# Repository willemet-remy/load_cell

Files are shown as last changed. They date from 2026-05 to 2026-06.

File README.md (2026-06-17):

# Beaker Load Cell Monitoring System

This repository contains the complete open-source hardware designs, ESP32 microcontroller firmware, and Python-based graphical user interface (GUI) for a 4-channel weight scale system. 

The system is designed to monitor the outflow of up to four 500 mL beakers filling gradually with water. It is suited for laboratory setups requiring continuous measurements, such as **constant-head saturated hydraulic conductivity ($K_{sat}$) measurements** of soil cores. By measuring the mass increase of the collected outflow over time, flow rates and hydraulic conductivity can be precisely and automatically calculated.

In addition, the GUI support a clear calibration per sensors, to be able to see the calibration driven with time of the load cell.

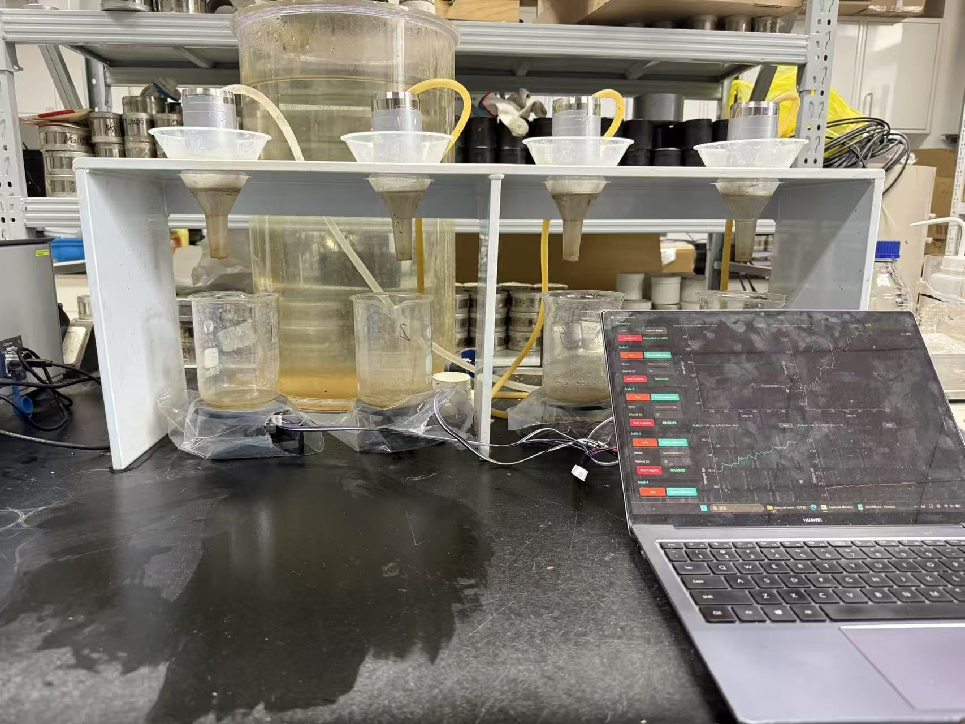
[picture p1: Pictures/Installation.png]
Physical Laboratory Setup


Physical lab setup
---

## Directory Structure

* [3D_model/](3D_model/)
  * Fusion 360 source designs (`.f3d`), STEP files, and STL files for 3D-printing the beaker support structures.

* [MCU_scr/](MCU_scr/)
  * PlatformIO project containing the C++ ESP32 firmware.

* [Software/](Software/)
  * Python PyQt6 desktop GUI application for real-time plotting, scaling, taring, and logging.

* [Pictures/](Pictures/)
  * Photographs of the physical setup and software interface.

* [data/](data/)
  * Target folder where calibration files and measurement logs (`.csv`) are saved.
---

## Bill of Materials (BOM)

| Item | Quantity | Description | Est. Cost (approx.) |
| :--- | :---: | :--- | :--- |
| **ESP32 DevKitC** | 1 | Microcontroller for sensor communication and serial data output. | 65 RMB |
| **1kg Load Cells** | 4 | Straight-beam load cells (TAL220). 1kg capacity is selected to accommodate the 500 mL water volume (~500g) plus the tare weight of the glass beaker (~150-200g). | 50 RMB / pc |
| **HX711 Amplifiers** | 4 | 24-bit Analog-to-Digital Converter (ADC) modules for weigh scales. | 39 RMB / pc |
| **3D-Printed Supports**| 4 sets | Two plates per load cell (base plate and beaker platform) to mount sensors. | 3D Printed |
| **M4 / M5 Screws & Spacers** | 1 set | Screws, nuts, and spacers to mount the load cells in a cantilever ("Z") configuration. | Generic |
| **Jumper Wires** | 1 pack | Dupont wires for connecting modules to the ESP32. | Generic |
| **Micro-USB Cable** | 1 | Cable for serial communication and ESP32 power. | Generic |

---

## Experiemental setup Setup

Each load cell must be mounted in a cantilever ("Z" structure) configuration to allow bending under weight. The 3D-printed plates ensure stable mounting of the load cells and the beakers.

### Technical Schematic
Below is the technical schematic of the 3D-printed support plate:

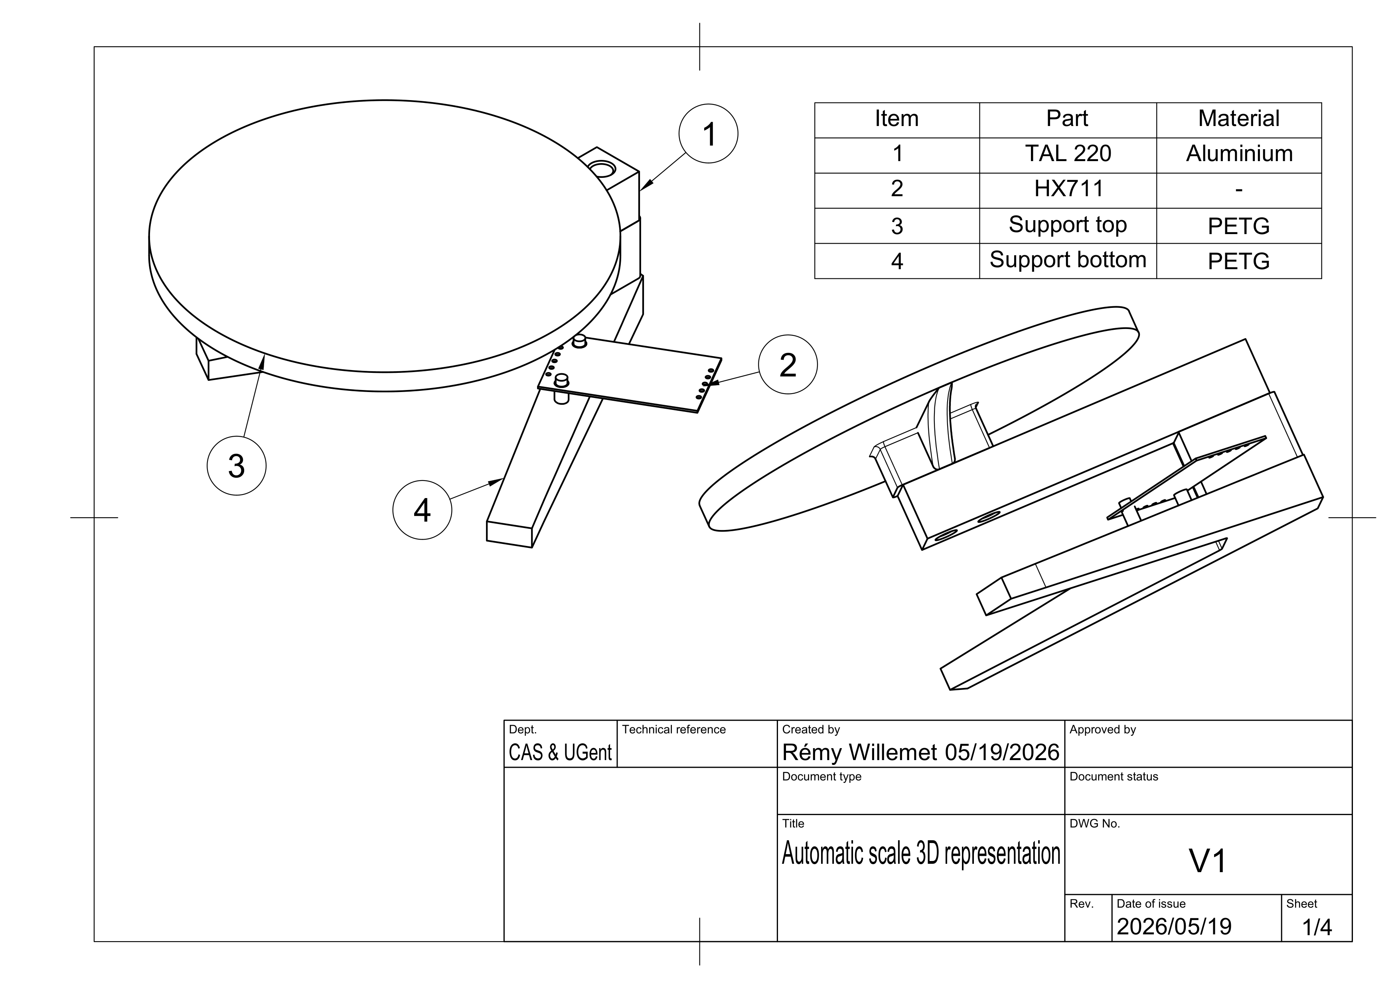
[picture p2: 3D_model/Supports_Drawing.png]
3D Model Support Drawing


### Sensor Mounting Detail
Close-up view of the 3D-printed support mount:

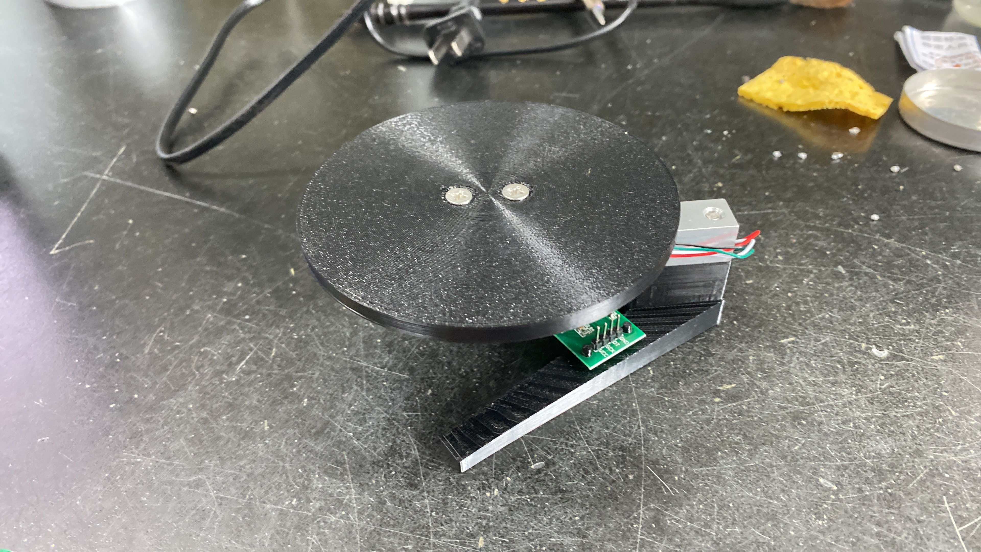
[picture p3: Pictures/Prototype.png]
Installation Setup Detail


### Desktop GUI Software
The user interface displaying real-time data from the 4 scales:

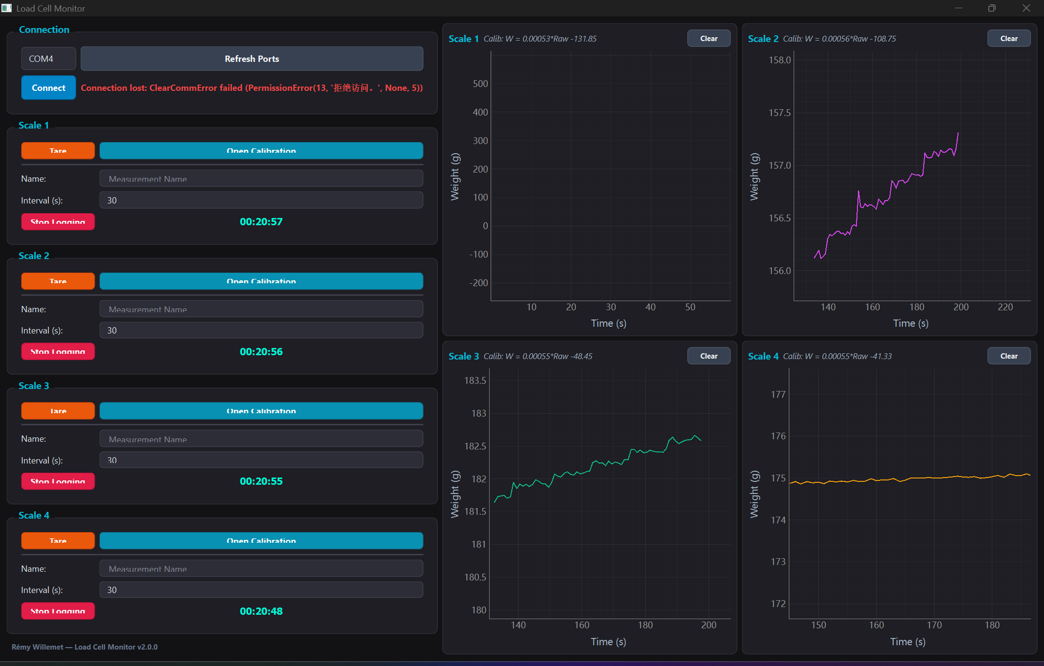
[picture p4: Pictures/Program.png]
Desktop GUI Interface


*The CAD source files (`.f3d`) and 3D-printable files (`.stl`) can be found in the [3D_model/](file:///3D_model/) folder.*

---

## Wiring Connections

### 1. Load Cell to HX711 Amplifier
Connect each load cell's Wheatstone bridge wires to its dedicated HX711 amplifier module:

| Load Cell Wire Color | HX711 Pin | Function |
| :--- | :--- | :--- |
| **Red** | E+ | Excitation Plus |
| **Black** | E- | Excitation Minus |
| **White** | A- | Signal Minus |
| **Green** | A+ | Signal Plus |

### 2. HX711 Amplifiers to ESP32 DevKitC
The ESP32 uses 3.3V logic. Power the HX711 modules using the 3.3V pin from the ESP32 to ensure safe logic levels.

| HX711 Pin | ESP32 Pin (GPIO) | Description |
| :--- | :--- | :--- |
| VCC / VDD | 3V3 | Power (3.3V Logic) |
| GND | GND | Ground |
| **Module 1 DT** | GPIO 16 | Scale 1 Data Line |
| **Module 1 SCK**| GPIO 17 | Scale 1 Clock Line |
| **Module 2 DT** | GPIO 18 | Scale 2 Data Line |
| **Module 2 SCK**| GPIO 19 | Scale 2 Clock Line |
| **Module 3 DT** | GPIO 22 | Scale 3 Data Line |
| **Module 3 SCK**| GPIO 23 | Scale 3 Clock Line |
| **Module 4 DT** | GPIO 32 | Scale 4 Data Line |
| **Module 4 SCK**| GPIO 33 | Scale 4 Clock Line |

---

## Installation & Usage

### 1. Microcontroller Firmware Setup
1. Install [PlatformIO IDE](https://platformio.org/) (either via VS Code extension or standalone command line).
2. Open the [MCU_scr/](file:///MCU_scr/) folder in PlatformIO.
3. Connect the ESP32 to your computer via USB.
4. Build and flash the firmware using the PlatformIO interface or by running:
   ```bash
   pio run --target upload
   ```

### 2. Python GUI Setup
1. Double-click the `install.bat` file in the main repository directory. This script will install Python dependencies (PyQt6, pyqtgraph, pyserial).
2. Alternatively, run the following in your terminal:
   ```bash
   pip install -r Software/requirements.txt
   ```

### 3. Running the System
1. Run the system using `Run_Load_Cell.bat` or by executing:
   ```bash
   python Software/main.py
   ```
2. Select the correct **COM Port** from the dropdown menu, choose a baudrate (115200), and click **Connect**.
3. **Tare & Calibration**:
   * Clear the scale platform and click **Tare** for the target scale.
   * Place a known calibration weight on the platform, enter the weight (in grams) in the input box next to **Calibrate**, and click **Calibrate**.
   * Calibration factors are stored automatically so they persist across runs.
4. **Logging**:
   * Enter a measurement name and logging interval (seconds).
   * Click **Start Logging** to begin saving to CSV.

---

## Data Logging Specification

Logged data is saved in CSV format. The CSV logs include:
*   `Timestamp`: Unix epoch time in seconds.
*   `Datetime`: Human-readable date and time (`YYYY-MM-DD HH:MM:SS`).
*   `Scale ID`: Scale indicator (`Scale 1` - `Scale 4`).
*   `Raw Value`: Raw 24-bit readings from the HX711.
*   `Weight (g)`: Calibrated weight reading in grams.

---

## License

This project is licensed under the MIT License - see the LICENSE file for details.

## Contact
**Rémy Willemet**
Research Institute for Agriculture, Fisheries and Food (ILVO)  
Email: [remy.willemet@ilvo.vlaanderen.be](mailto:remy.willemet@ilvo.vlaanderen.be)

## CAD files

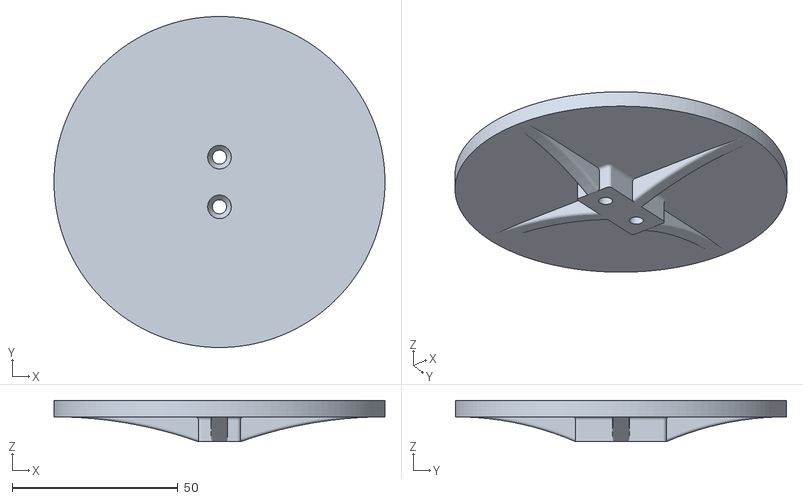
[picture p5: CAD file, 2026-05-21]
3D_model/Support_top.stl
100.0 x 100.0 x 12.5

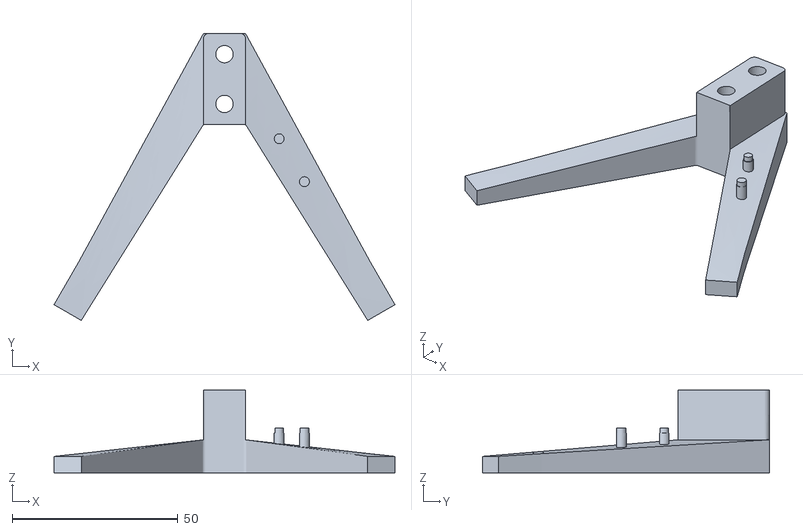
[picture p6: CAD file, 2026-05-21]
3D_model/Support_bottom.stl
102.8 x 86.4 x 25.0

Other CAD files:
3D_model/Support_bottom.f3d
3D_model/Support_top.f3d

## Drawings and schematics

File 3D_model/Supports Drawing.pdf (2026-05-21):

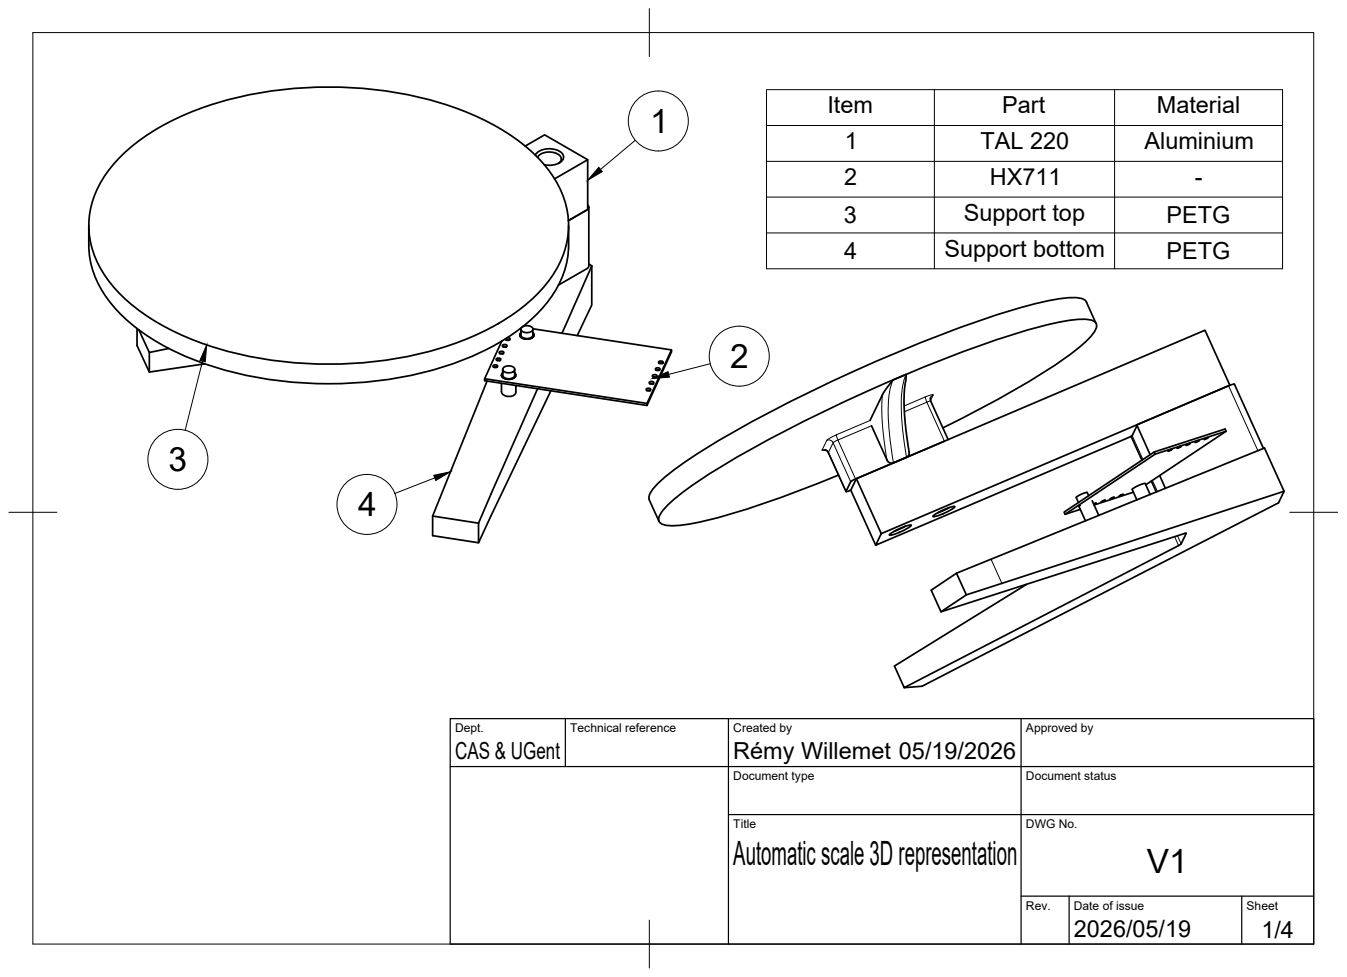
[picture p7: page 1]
Item; Part; Material 1

2 | TAL 220 HX711 | Aluminium - 1

3 | Support top | PETG
4 | Support bottom | PETG

Dept. CAS & UGent | Technical reference | Created by Rémy Willemet 05/19/2026 | Approved by

Document type | Document status

Title Automatic scale 3D representation | DWG No. V1

Rev. | Date of issue 2026/05/19 | Sheet

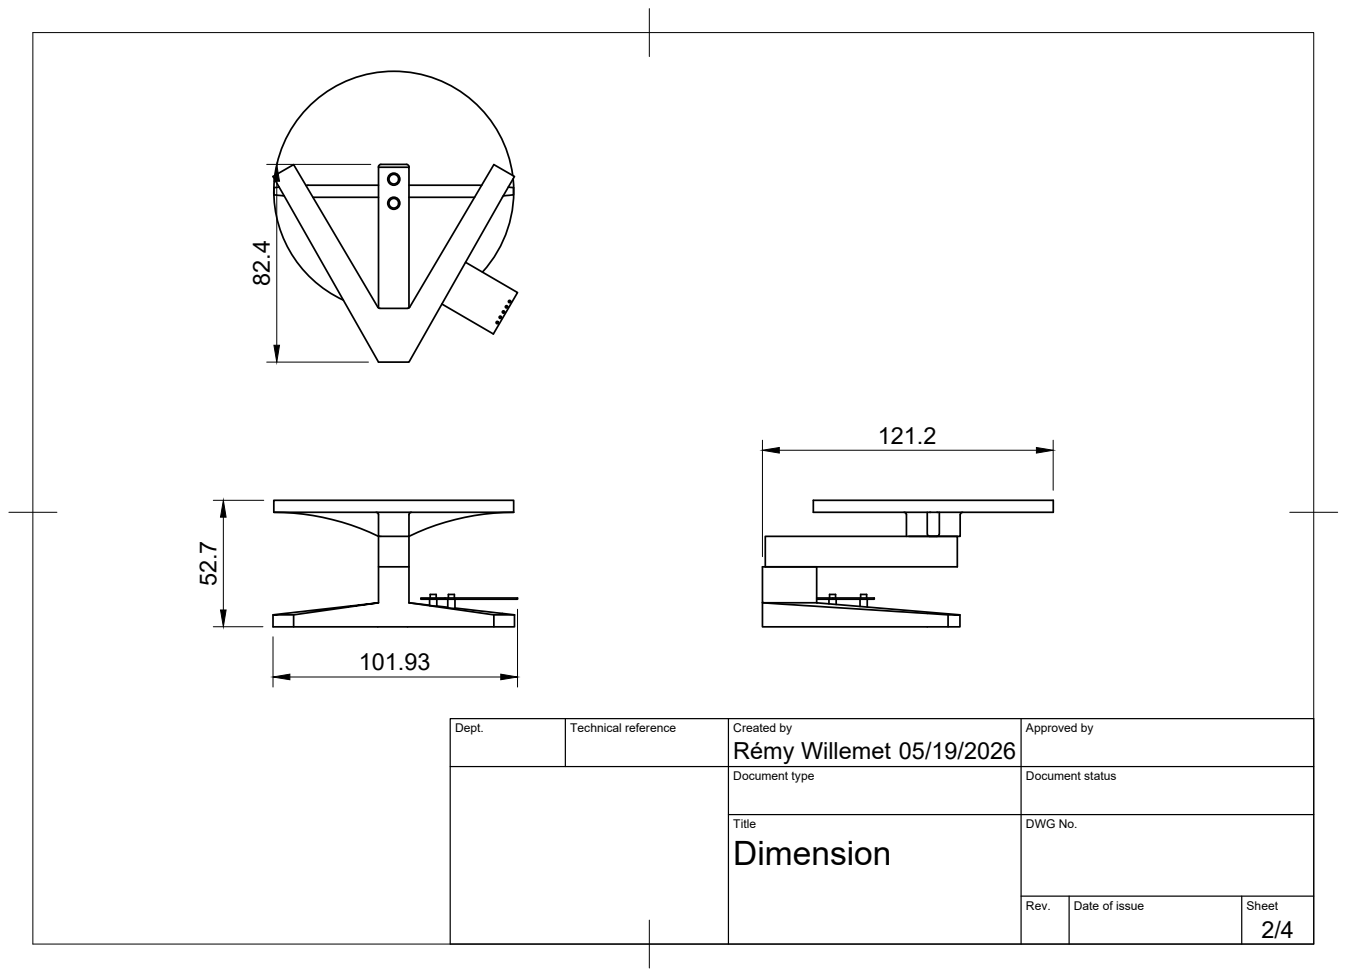
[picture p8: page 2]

Dept. | Technical reference | Created by Rémy Willemet 05/19/2026 | Approved by

Document type | Document status

Title Dimension | DWG No.

Rev. | Date of issue | Sheet

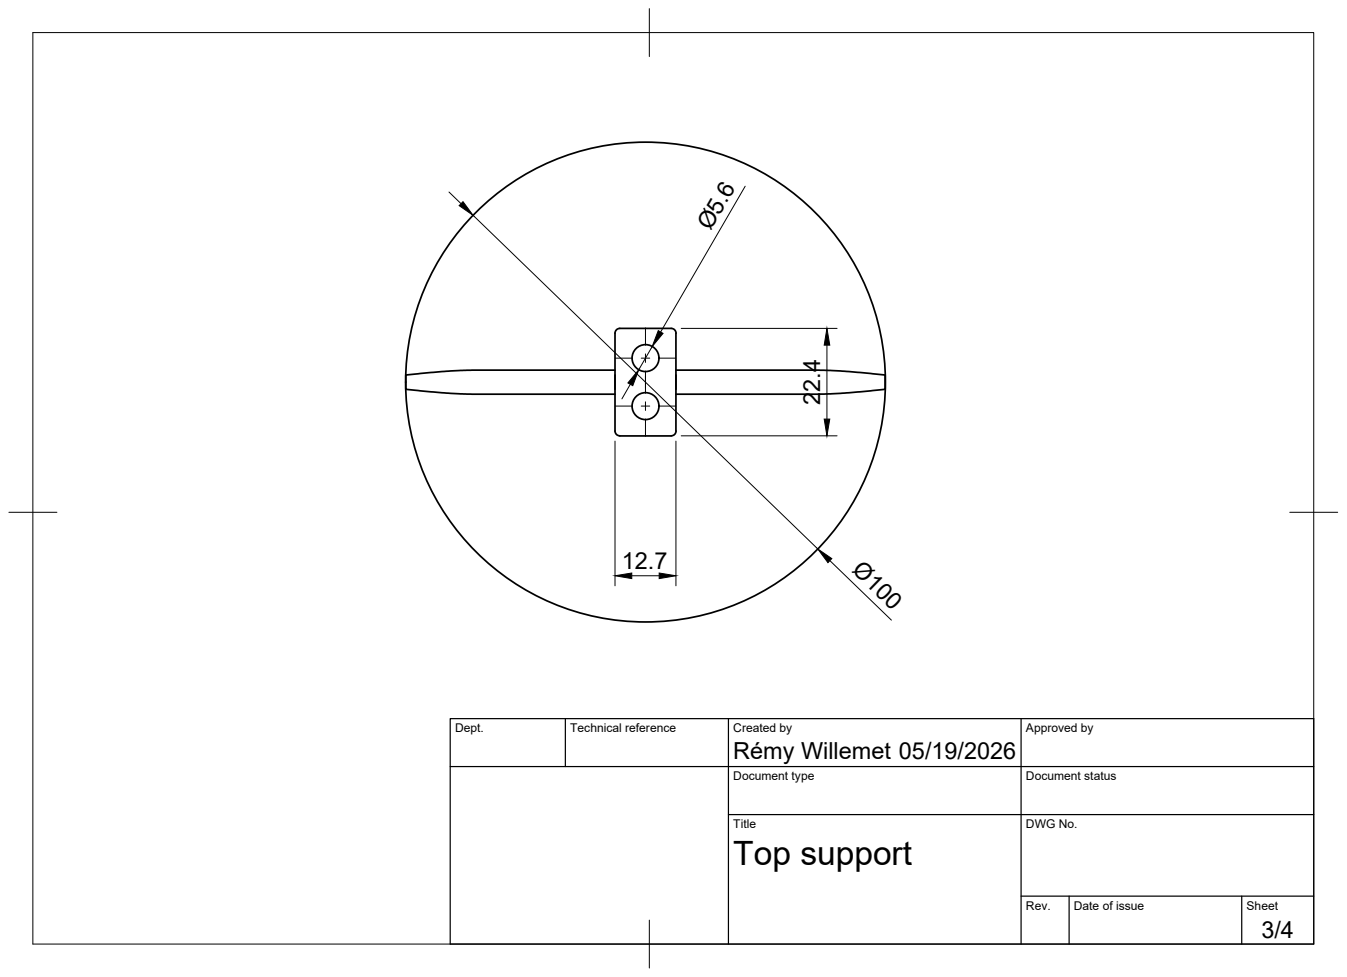
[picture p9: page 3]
Rémy Willemet 22.4

Dept. | Technical reference | Created by 05/19/2026 | Approved by

Document type | Document status

Title Top support | DWG No.

Rev. | Date of issue | Sheet

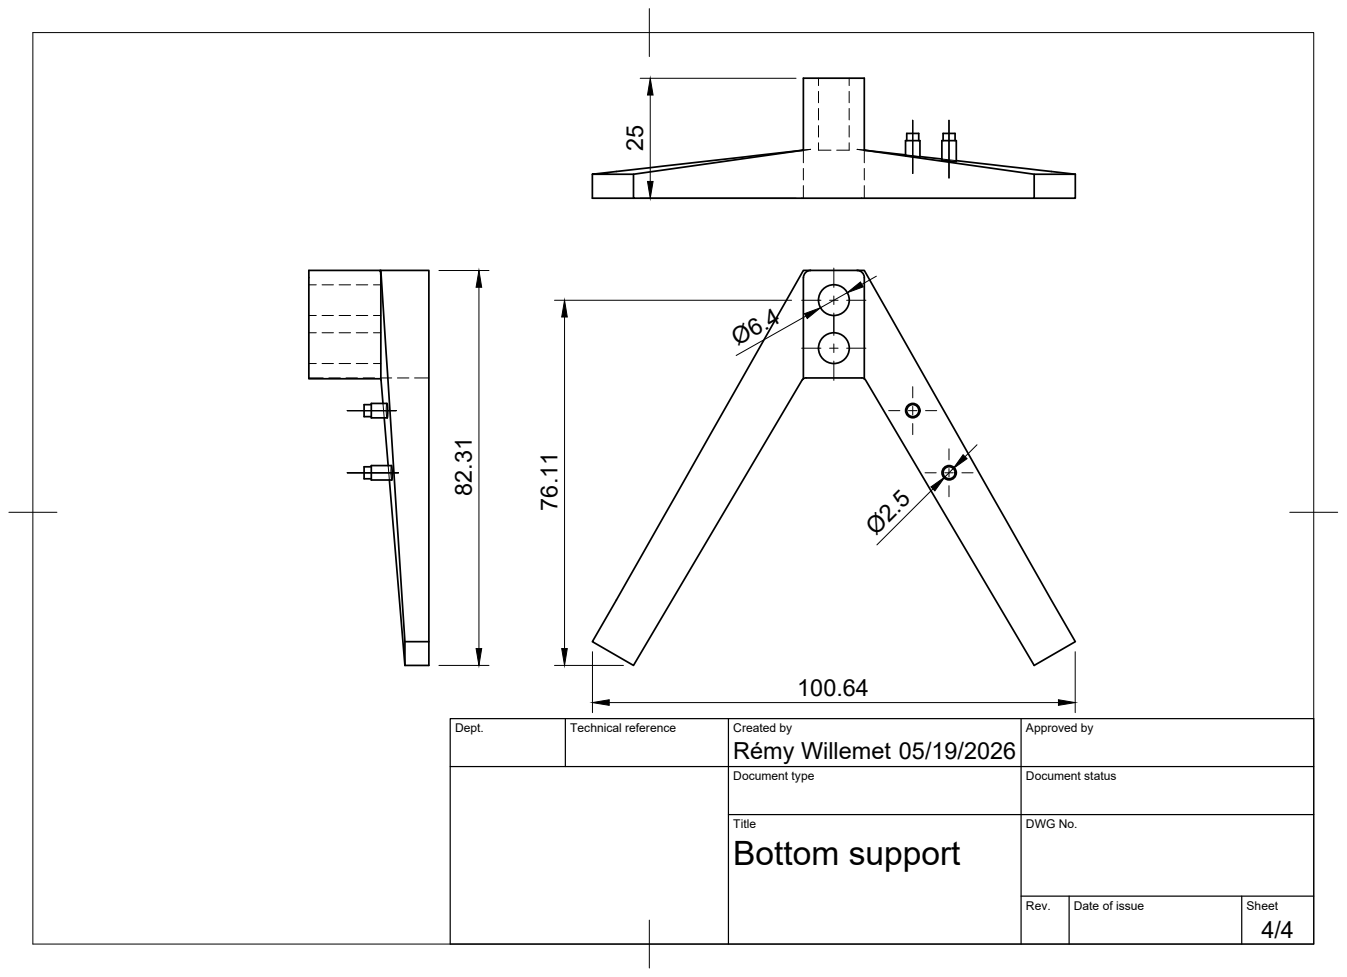
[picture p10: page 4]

Dept. | Technical reference | Created by Rémy Willemet 05/19/2026 | Approved by

Document type | Document status

Title Bottom support | DWG No.

Rev. | Date of issue | Sheet

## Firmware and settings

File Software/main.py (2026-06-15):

import sys
import time
import os
from PyQt6.QtWidgets import (QApplication, QMainWindow, QWidget, QVBoxLayout, QHBoxLayout,
                             QPushButton, QLabel, QLineEdit, QComboBox, QGroupBox, QSpinBox,
                             QGridLayout, QDoubleSpinBox, QFrame)
from PyQt6.QtCore import pyqtSlot, QTimer, Qt
from PyQt6.QtGui import QIcon
import pyqtgraph as pg

from serial_worker import SerialWorker
from data_logger import DataLogger
from calibration_dialog import CalibrationDialog

THEME_QSS = """
QMainWindow {
    background-color: #121214;
}

QDialog {
    background-color: #121214;
}

QWidget {
    font-family: 'Segoe UI', -apple-system, BlinkMacSystemFont, Roboto, Helvetica, Arial, sans-serif;
    color: #e2e8f0;
}

QGroupBox {
    background-color: #1e1e24;
    border: 1px solid #2e2e38;
    border-radius: 8px;
    margin-top: 12px;
    font-weight: bold;
    font-size: 13px;
    padding: 10px;
}

QGroupBox::title {
    subcontrol-origin: margin;
    subcontrol-position: top left;
    left: 10px;
    padding: 0 5px;
    color: #06b6d4;
}

/* Form Inputs */
QLineEdit, QSpinBox, QDoubleSpinBox, QComboBox {
    background-color: #2d2d38;
    border: 1px solid #3f3f4c;
    border-radius: 6px;
    padding: 6px 10px;
    color: #e2e8f0;
    font-size: 12px;
}

QLineEdit:focus, QSpinBox:focus, QDoubleSpinBox:focus, QComboBox:focus {
    border: 1px solid #06b6d4;
    background-color: #343442;
}

QComboBox::drop-down {
    subcontrol-origin: padding;
    subcontrol-position: top right;
    width: 20px;
    border-left-width: 0px;
    border-top-right-radius: 6px;
    border-bottom-right-radius: 6px;
}

/* Buttons */
QPushButton {
    background-color: #2d2d38;
    border: 1px solid #3f3f4c;
    border-radius: 6px;
    padding: 8px 12px;
    font-weight: bold;
    font-size: 12px;
    color: #e2e8f0;
}

QPushButton:hover {
    background-color: #3f3f50;
    border-color: #06b6d4;
}

QPushButton:pressed {
    background-color: #23232b;
}

QPushButton:disabled {
    background-color: #1a1a20;
    color: #64748b;
    border-color: #2a2a32;
}

/* Themes */
QPushButton[theme="primary"] {
    background-color: #0284c7;
    border: 1px solid #0369a1;
    color: white;
}
QPushButton[theme="primary"]:hover {
    background-color: #0369a1;
}

QPushButton[theme="accent"] {
    background-color: #ea580c;
    border: 1px solid #c2410c;
    color: white;
}
QPushButton[theme="accent"]:hover {
    background-color: #c2410c;
}

QPushButton[theme="info"] {
    background-color: #0891b2;
    border: 1px solid #0e7490;
    color: white;
}
QPushButton[theme="info"]:hover {
    background-color: #0e7490;
}

QPushButton[theme="success"] {
    background-color: #059669;
    border: 1px solid #047857;
    color: white;
}
QPushButton[theme="success"]:hover {
    background-color: #047857;
}

QPushButton[theme="danger"] {
    background-color: #e11d48;
    border: 1px solid #be123c;
    color: white;
}
QPushButton[theme="danger"]:hover {
    background-color: #be123c;
}

QPushButton[theme="secondary"] {
    background-color: #374151;
    border: 1px solid #4b5563;
    color: #f3f4f6;
}
QPushButton[theme="secondary"]:hover {
    background-color: #4b5563;
}

/* Status styling */
QLabel[status="connected"] {
    color: #10b981;
    font-weight: bold;
}
QLabel[status="connecting"] {
    color: #f59e0b;
    font-weight: bold;
}
QLabel[status="disconnected"] {
    color: #ef4444;
    font-weight: bold;
}

/* Table Widget styling */
QTableWidget {
    background-color: #1e1e24;
    border: 1px solid #2e2e38;
    gridline-color: #2e2e38;
    border-radius: 6px;
    color: #e2e8f0;
}

QTableWidget::item {
    padding: 5px;
}

QTableWidget::item:selected {
    background-color: #06b6d4;
    color: white;
}

QHeaderView::section {
    background-color: #2d2d38;
    color: #e2e8f0;
    padding: 6px;
    border: 1px solid #2e2e38;
    font-weight: bold;
}

QScrollBar:vertical {
    border: none;
    background: #121214;
    width: 8px;
    margin: 0px;
}

QScrollBar::handle:vertical {
    background: #3f3f4c;
    min-height: 20px;
    border-radius: 4px;
}

QScrollBar::handle:vertical:hover {
    background: #06b6d4;
}

QScrollBar::add-line:vertical, QScrollBar::sub-line:vertical {
    border: none;
    background: none;
}

QFrame#plot_container {
    background-color: #1e1e24;
    border: 1px solid #2e2e38;
    border-radius: 8px;
}
"""

class MainWindow(QMainWindow):
    def __init__(self):
        super().__init__()
        self.setWindowTitle("Load Cell Monitor")
        self.resize(1200, 800)
        
        icon_path = os.path.join(os.path.dirname(os.path.abspath(__file__)), "..", "icon.png")
        if os.path.exists(icon_path):
            self.setWindowIcon(QIcon(icon_path))
            
        self.logger = DataLogger()
        self.calibration_data = self.logger.load_calibration() or {}
        self.active_calib_dialogs = [None] * 4
        self.serial_worker = SerialWorker()
        self.serial_worker.data_received.connect(self.on_data_received)
        self.serial_worker.connection_status.connect(self.on_connection_status)
        
        # Data buffers for plotting
        self.start_times = [time.time()] * 4
        self.time_data = [[], [], [], []]
        self.weight_data = [[], [], [], []]
        self.curves = []
        
        self.scale_controls = []
        self.logging_start_times = [None] * 4
        
        # Setup UI update timer for elapsed logging time
        self.ui_timer = QTimer(self)
        self.ui_timer.timeout.connect(self.update_logging_timers)
        self.ui_timer.start(1000)
        
        self.init_ui()
        self.refresh_ports()
        
    def init_ui(self):
        main_widget = QWidget()
        self.setCentralWidget(main_widget)
        main_layout = QHBoxLayout(main_widget)
        
        # Left Panel (Controls)
        left_panel = QVBoxLayout()
        
        # Connection Group
        conn_group = QGroupBox("Connection")
        conn_layout = QGridLayout()
        self.port_combo = QComboBox()
        self.btn_refresh = QPushButton("Refresh Ports")
        self.btn_refresh.setProperty("theme", "secondary")
        self.btn_refresh.clicked.connect(self.refresh_ports)
        self.btn_connect = QPushButton("Connect")
        self.btn_connect.setProperty("theme", "primary")
        self.btn_connect.clicked.connect(self.toggle_connection)
        
        self.lbl_status = QLabel("Disconnected")
        self.lbl_status.setObjectName("lbl_status")
        self.lbl_status.setProperty("status", "disconnected")
        self.lbl_status.setAlignment(Qt.AlignmentFlag.AlignCenter)
        
        conn_layout.addWidget(self.port_combo, 0, 0)
        conn_layout.addWidget(self.btn_refresh, 0, 1)
        conn_layout.addWidget(self.btn_connect, 1, 0)
        conn_layout.addWidget(self.lbl_status, 1, 1)
        conn_group.setLayout(conn_layout)
        left_panel.addWidget(conn_group)
        
        # Scale Controls Group
        scales_layout = QVBoxLayout()
        
        for i in range(4):
            cal_group = QGroupBox(f"Scale {i+1}")
            cal_layout = QGridLayout()
            
            # Tare / Calibrate
            btn_tare = QPushButton("Tare")
            btn_tare.setProperty("theme", "accent")
            btn_tare.clicked.connect(lambda checked, idx=i: self.tare_scale(idx))
            
            btn_cal = QPushButton("Open Calibration")
            btn_cal.setProperty("theme", "info")
            btn_cal.clicked.connect(lambda checked, idx=i: self.open_calibration(idx))
            
            # Measurement Logging
            le_meas_name = QLineEdit()
            le_meas_name.setPlaceholderText("Measurement Name")
            
            cb_interval = QComboBox()
            cb_interval.addItems(["5", "10", "15", "30", "60", "120"])
            cb_interval.setCurrentText("30")
            
            btn_start_stop = QPushButton("Start Logging")
            btn_start_stop.setProperty("theme", "success")
            btn_start_stop.clicked.connect(lambda checked, idx=i: self.toggle_logging(idx))
            
            lbl_timer = QLabel("00:00:00")
            lbl_timer.setAlignment(Qt.AlignmentFlag.AlignCenter)
            lbl_timer.setStyleSheet("font-family: monospace; font-size: 13px; color: #888888; font-weight: bold;")
            
            # Layout logic
            cal_layout.addWidget(btn_tare, 0, 0)
            cal_layout.addWidget(btn_cal, 0, 1)
            
            # Add a separator line
            line = QWidget()
            line.setFixedHeight(2)
            line.setStyleSheet("background-color: #3f3f4c;")
            cal_layout.addWidget(line, 1, 0, 1, 2)
            
            cal_layout.addWidget(QLabel("Name:"), 2, 0)
            cal_layout.addWidget(le_meas_name, 2, 1)
            cal_layout.addWidget(QLabel("Interval (s):"), 3, 0)
            cal_layout.addWidget(cb_interval, 3, 1)
            cal_layout.addWidget(btn_start_stop, 4, 0)
            cal_layout.addWidget(lbl_timer, 4, 1)
            
            self.scale_controls.append({
                'le_name': le_meas_name,
                'cb_interval': cb_interval,
                'btn_start_stop': btn_start_stop,
                'lbl_timer': lbl_timer
            })
            
            cal_group.setLayout(cal_layout)
            scales_layout.addWidget(cal_group)
            
        left_panel.addLayout(scales_layout)
        left_panel.addStretch()
        
        # Version Label
        lbl_version = QLabel("Rémy Willemet — Load Cell Monitor v2.0.0")
        lbl_version.setStyleSheet("color: #64748b; font-size: 10px; font-weight: bold; padding: 4px;")
        left_panel.addWidget(lbl_version)
        
        main_layout.addLayout(left_panel, 1)
        
        # Right Panel (Plots)
        plot_layout = QGridLayout()
        self.plots = []
        self.curves = []
        self.plot_calib_labels = []
        
        for i in range(4):
            # Create QFrame container for the plot card
            plot_container = QFrame()
            plot_container.setObjectName("plot_container")
            container_layout = QVBoxLayout(plot_container)
            container_layout.setContentsMargins(8 , 8, 8, 8)
            container_layout.setSpacing(5)
            
            # Header
            header_layout = QHBoxLayout()
            lbl_title = QLabel(f"Scale {i+1}")
            lbl_title.setStyleSheet("font-size: 13px; font-weight: bold; color: #06b6d4;")
            
            lbl_calib = QLabel("")
            lbl_calib.setStyleSheet("font-size: 11px; color: #a0aec0; font-style: italic; font-weight: normal;")
            
            btn_clear = QPushButton("Clear")
            btn_clear.setProperty("theme", "secondary")
            btn_clear.setFixedWidth(60)
            btn_clear.setFixedHeight(24)
            btn_clear.setStyleSheet("font-size: 10px; padding: 2px 5px;")
            btn_clear.clicked.connect(lambda checked, idx=i: self.clear_scale_graph(idx))
            
            header_layout.addWidget(lbl_title)
            header_layout.addWidget(lbl_calib)
            header_layout.addStretch()
            header_layout.addWidget(btn_clear)
            container_layout.addLayout(header_layout)
            
            # Plot Widget
            plot = pg.PlotWidget()
            plot.setBackground('#1e1e24')
            plot.getAxis('left').setPen(pg.mkPen(color='#888888', width=1))
            plot.getAxis('bottom').setPen(pg.mkPen(color='#888888', width=1))
            plot.showGrid(x=True, y=True, alpha=0.15)
            plot.setXRange(0, 60, padding=0)
            
            label_style = {'color': '#a0aec0', 'font-size': '10pt'}
            plot.setLabel('left', 'Weight (g)', **label_style)
            plot.setLabel('bottom', 'Time (s)', **label_style)
            
            # Neon palette
            colors = [
                (6, 182, 212),   # Cyan
                (217, 70, 239),  # Magenta/Purple
                (16, 185, 129),  # Emerald
                (245, 158, 11)   # Orange
            ]
            curve = plot.plot(pen=pg.mkPen(color=colors[i], width=2))
            
            container_layout.addWidget(plot)
            
            self.plots.append(plot)
            self.curves.append(curve)
            self.plot_calib_labels.append(lbl_calib)
            
            row = i // 2
            col = i % 2
            plot_layout.addWidget(plot_container, row, col)
            
        main_layout.addLayout(plot_layout, 4)
    def refresh_ports(self):
        self.port_combo.clear()
        ports = self.serial_worker.get_available_ports()
        self.port_combo.addItems(ports)
        
    def toggle_connection(self):
        if self.serial_worker.is_running:
            self.btn_connect.setEnabled(False)
            self.lbl_status.setText("Disconnecting...")
            self.lbl_status.setProperty("status", "connecting")
            self.lbl_status.style().unpolish(self.lbl_status)
            self.lbl_status.style().polish(self.lbl_status)
            self.serial_worker.disconnect_port()
        else:
            port = self.port_combo.currentText()
            if port:
                self.btn_connect.setEnabled(False)
                self.lbl_status.setText("Connecting...")
                self.lbl_status.setProperty("status", "connecting")
                self.lbl_status.style().unpolish(self.lbl_status)
                self.lbl_status.style().polish(self.lbl_status)
                self.serial_worker.connect_port(port)
                
    @pyqtSlot(bool, str)
    def on_connection_status(self, connected, msg):
        self.lbl_status.setText(msg)
        self.btn_connect.setEnabled(True)
        if connected:
            self.btn_connect.setText("Disconnect")
            self.btn_connect.setProperty("theme", "danger")
            self.lbl_status.setProperty("status", "connected")
            for scale_idx, calib in self.calibration_data.items():
                if 'factor' in calib and 'offset' in calib:
                    self.serial_worker.send_command({
                        "cmd": "SET_CALIBRATION",
                        "scale": int(scale_idx),
                        "factor": calib['factor'],
                        "offset": calib['offset']
                    })
        else:
            self.btn_connect.setText("Connect")
            self.btn_connect.setProperty("theme", "primary")
            self.lbl_status.setProperty("status", "disconnected")
            
        self.btn_connect.style().unpolish(self.btn_connect)
        self.btn_connect.style().polish(self.btn_connect)
        self.lbl_status.style().unpolish(self.lbl_status)
        self.lbl_status.style().polish(self.lbl_status)
            
    @pyqtSlot(dict)
    def on_data_received(self, data):
        if 'type' in data and data['type'] == 'DATA':
            # Update logger
            self.logger.process_data(data)
            
            # Update plots
            for i in range(4):
                current_t = time.time() - self.start_times[i]
                self.time_data[i].append(current_t)
                self.weight_data[i].append(data['weight'][i])
            
                # Keep exactly last 60 seconds of data (with 5s buffer to prevent edge cutting)
                while self.time_data[i] and (current_t - self.time_data[i][0] > 65.0):
                    self.time_data[i].pop(0)
                    self.weight_data[i].pop(0)
                    
                x_min = max(0.0, current_t - 60.0)
                x_max = max(60.0, current_t)
                
                self.curves[i].setData(self.time_data[i], self.weight_data[i])
                self.plots[i].setXRange(x_min, x_max, padding=0)
                
                if self.active_calib_dialogs[i] is not None:
                    self.active_calib_dialogs[i].update_live_data(i, data['raw'][i])

        elif 'status' in data:
            if data['status'] == 'CALIBRATED':
                self.logger.log_calibration_history(data)
            print(f"Status update from MCU: {data}")

    def clear_scale_graph(self, scale_idx):
        self.start_times[scale_idx] = time.time()
        self.time_data[scale_idx].clear()
        self.weight_data[scale_idx].clear()
        self.curves[scale_idx].setData([], [])
        self.plots[scale_idx].setXRange(0.0, 60.0, padding=0)

    def clear_graphs(self):
        for i in range(4):
            self.clear_scale_graph(i)

    def update_logging_timers(self):
        for i in range(4):
            start_time = self.logging_start_times[i]
            controls = self.scale_controls[i]
            if start_time is not None:
                elapsed = int(time.time() - start_time)
                hours, remainder = divmod(elapsed, 3600)
                minutes, seconds = divmod(remainder, 60)
                time_str = f"{hours:02d}:{minutes:02d}:{seconds:02d}"
                controls['lbl_timer'].setText(time_str)
                controls['lbl_timer'].setStyleSheet("font-family: monospace; font-size: 13px; color: #00f5d4; font-weight: bold;")
            else:
                controls['lbl_timer'].setText("00:00:00")
                controls['lbl_timer'].setStyleSheet("font-family: monospace; font-size: 13px; color: #888888; font-weight: bold;")

    def toggle_logging(self, scale_idx):
        controls = self.scale_controls[scale_idx]
        state = self.logger.scale_states[scale_idx]
        
        if state['is_logging']:
            self.logger.stop_logging(scale_idx)
            self.logging_start_times[scale_idx] = None
            controls['btn_start_stop'].setText("Start Logging")
            controls['btn_start_stop'].setProperty("theme", "success")
            controls['le_name'].setEnabled(True)
            controls['cb_interval'].setEnabled(True)
            controls['lbl_timer'].setText("00:00:00")
            controls['lbl_timer'].setStyleSheet("font-family: monospace; font-size: 13px; color: #888888; font-weight: bold;")
            
            # Clear calibration equation text when logging stops
            self.plot_calib_labels[scale_idx].setText("")
        else:
            name = controls['le_name'].text()
            interval = int(controls['cb_interval'].currentText())
            self.logger.start_logging(scale_idx, name, interval)
            self.logging_start_times[scale_idx] = time.time()
            self.clear_scale_graph(scale_idx)
            controls['btn_start_stop'].setText("Stop Logging")
            controls['btn_start_stop'].setProperty("theme", "danger")
            controls['le_name'].setEnabled(False)
            controls['cb_interval'].setEnabled(False)
            controls['lbl_timer'].setText("00:00:00")
            controls['lbl_timer'].setStyleSheet("font-family: monospace; font-size: 13px; color: #00f5d4; font-weight: bold;")
            
            # Show calibration curve equation when logging starts
            calib = self.calibration_data.get(str(scale_idx))
            if calib and 'factor' in calib and 'offset' in calib:
                factor = calib['factor']
                offset = calib['offset']
                if factor != 0:
                    m = 1.0 / factor
                    c = -offset / factor
                    eq_str = f"Calib: W = {m:.5f}*Raw {c:+.2f}"
                    self.plot_calib_labels[scale_idx].setText(eq_str)
            else:
                self.plot_calib_labels[scale_idx].setText("Calib: Not calibrated")
            
        controls['btn_start_stop'].style().unpolish(controls['btn_start_stop'])
        controls['btn_start_stop'].style().polish(controls['btn_start_stop'])
            
    def tare_scale(self, scale_idx):
        self.serial_worker.send_command({"cmd": "TARE", "scale": scale_idx})
        
    def open_calibration(self, scale_idx):
        if self.active_calib_dialogs[scale_idx] is not None:
            self.active_calib_dialogs[scale_idx].activateWindow()
            return
            
        initial_data = self.calibration_data.get(str(scale_idx))
        dialog = CalibrationDialog(scale_idx, self, initial_calib_data=initial_data)
        self.active_calib_dialogs[scale_idx] = dialog
        
        if dialog.exec():
            calib = dialog.get_calibration_data()
            self.calibration_data[str(scale_idx)] = calib
            self.logger.save_calibration(self.calibration_data)
            
            if self.serial_worker.is_running:
                self.serial_worker.send_command({
                    "cmd": "SET_CALIBRATION",
                    "scale": scale_idx,
                    "factor": calib['factor'],
                    "offset": calib['offset']
                })
            
        self.active_calib_dialogs[scale_idx] = None

    def closeEvent(self, event):
        self.serial_worker.disconnect_port()
        event.accept()

if __name__ == '__main__':
    app = QApplication(sys.argv)
    app.setStyleSheet(THEME_QSS)
    window = MainWindow()
    window.show()
    sys.exit(app.exec())

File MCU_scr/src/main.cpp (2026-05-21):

#include <Arduino.h>
#include <HX711.h>
#include <ArduinoJson.h>

// Pins for the 4 load cells (Data, Clock)
const int DT_PINS[4]  = {16, 18, 22, 32};
const int SCK_PINS[4] = {17, 19, 23, 33};

HX711 scales[4];

// Current calibration factors and offsets (can be updated via serial)
float calibration_factors[4] = {1.0, 1.0, 1.0, 1.0};
long offsets[4] = {0, 0, 0, 0};

unsigned long lastTime = 0;
const unsigned long timerDelay = 1000; // 1Hz data streaming

void initScales() {
  for (int i = 0; i < 4; i++) {
    scales[i].begin(DT_PINS[i], SCK_PINS[i]);
    scales[i].set_scale(calibration_factors[i]);
    scales[i].set_offset(offsets[i]);
  }
}

// Tare a specific scale and send response
void tareScale(int scaleIdx) {
  scales[scaleIdx].tare();
  offsets[scaleIdx] = scales[scaleIdx].get_offset();
  
  JsonDocument resp;
  resp["status"] = "TARED";
  resp["scale"] = scaleIdx;
  resp["offset"] = offsets[scaleIdx];
  serializeJson(resp, Serial);
  Serial.println();
}

// Calibrate a specific scale using a known weight and send response
void calibrateScale(int scaleIdx, float known_weight) {
  if (known_weight > 0) {
    // get_value(10) gets average of 10 raw readings minus the offset
    long raw_val = scales[scaleIdx].get_value(10); 
    calibration_factors[scaleIdx] = (float)raw_val / known_weight;
    scales[scaleIdx].set_scale(calibration_factors[scaleIdx]);
    
    JsonDocument resp;
    resp["status"] = "CALIBRATED";
    resp["scale"] = scaleIdx;
    resp["factor"] = calibration_factors[scaleIdx];
    resp["raw"] = raw_val;
    resp["weight"] = known_weight;
    serializeJson(resp, Serial);
    Serial.println();
  }
}

// Force a calibration factor and offset from PC config
void setCalibration(int scaleIdx, float factor, long offset) {
  calibration_factors[scaleIdx] = factor;
  offsets[scaleIdx] = offset;
  scales[scaleIdx].set_scale(factor);
  scales[scaleIdx].set_offset(offset);
  
  JsonDocument resp;
  resp["status"] = "CALIBRATION_SET";
  resp["scale"] = scaleIdx;
  serializeJson(resp, Serial);
  Serial.println();
}

void processSerialCommand() {
  if (Serial.available() > 0) {
    String cmd = Serial.readStringUntil('\n');
    cmd.trim();
    if (cmd.length() == 0) return;

    // Incoming JSON command format:
    // {"cmd": "TARE", "scale": 0}
    // {"cmd": "CALIBRATE", "scale": 0, "weight": 500.0}
    // {"cmd": "SET_CALIBRATION", "scale": 0, "factor": 250.5, "offset": 8345}
    JsonDocument doc;
    DeserializationError error = deserializeJson(doc, cmd);
    
    if (error) {
      Serial.println("{\"error\": \"Invalid JSON command\"}");
      return;
    }

    String action = doc["cmd"].as<String>();
    int scaleIdx = doc["scale"].as<int>();

    if (scaleIdx >= 0 && scaleIdx < 4) {
      if (action == "TARE") {
        tareScale(scaleIdx);
      } 
      else if (action == "CALIBRATE") {
        calibrateScale(scaleIdx, doc["weight"].as<float>());
      }
      else if (action == "SET_CALIBRATION") {
        setCalibration(scaleIdx, doc["factor"].as<float>(), doc["offset"].as<long>());
      }
    }
  }
}

void sendData() {
  JsonDocument doc;
  doc["type"] = "DATA";
  doc["timestamp"] = millis();
  
  JsonArray rawArr = doc["raw"].to<JsonArray>();
  JsonArray weightArr = doc["weight"].to<JsonArray>();

  for (int i = 0; i < 4; i++) {
    if (scales[i].is_ready()) {
      long raw = scales[i].read(); // absolute raw reading
      float weight = scales[i].get_units(1); // 1 sample with applied scale/offset
      rawArr.add(raw);
      weightArr.add(weight);
    } else {
      rawArr.add(0);
      weightArr.add(0.0);
    }
  }

  serializeJson(doc, Serial);
  Serial.println();
}

void setup() {
  Serial.begin(115200);
  initScales();
}

void loop() {
  processSerialCommand();

  unsigned long currentMillis = millis();
  if (currentMillis - lastTime >= timerDelay) {
    sendData();
    lastTime = currentMillis;
  }
}

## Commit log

2026-05-13 3D model added
    [Support_bottom.f3d, Support_top.f3d]
2026-05-21 V1 finish, add easy installation
    [20260519_101643_Measurement_Scale1_Scale1.csv, Support_bottom.stl, Support_top.stl]
2026-05-26 add calibration window and new style
2026-06-15 improvement software and data save
    [20260615_094421_57_Scale1.csv, 20260615_094638_57_Scale1.csv, 20260615_094654_57_Scale1.csv]
